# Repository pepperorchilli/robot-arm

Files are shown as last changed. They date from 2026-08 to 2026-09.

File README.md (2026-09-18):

# 五自由度机械臂 · 项目存档

本仓库包含机械臂项目的**两个阶段版本**，用于呈现完整的技术演进过程。

```
robot-arm 1/     2026-08-16 的版本（第一代）
robot-arm2/      当前版本（第二代）
```

---

## 为什么有两个版本

这不是"新旧替换"，而是**两次架构决策前后**的对比记录。

| | robot-arm 1 | robot-arm2 |
|---|---|---|
| **时间** | 2026-08-11 ~ 08-16 | 2026-09-18 起 |
| **定位** | 打通云端链路，实现公网遥控 | 解决抖动、补齐工程化 |
| **舵机驱动** | PCA9685 + 模拟舵机 | 升级中：总线舵机（STS3215） |
| **前端** | 原生 HTML/CSS/JS | Vue 3 + Vite |
| **数据存储** | JSON 文件 | MySQL |
| **接口文档** | 无 | OpenAPI / Swagger |
| **附加功能** | 官网 / 留言板 / PWA | 手势识别 / 力反馈接口 |

**关键差异**：第一代把系统"跑起来"了，但在静止时发现 5 个舵机会小幅抽搐——
根因是模拟舵机的脉宽被 WiFi 射频干扰。第二代换了**串行总线舵机**，
用带校验和的数字协议从**协议层免疫**这个问题，同时获得力反馈能力。

---

## 📁 robot-arm 1 —— 第一代（2026-08-16）

```
robot-arm 1/
├── 3D建模/              六个结构件的 STL（MG996R 尺寸，正在重新建模）
├── server/              云控服务器 + 官网（Node.js，JSON 存储）
├── servo-test/          基础固件（softAP 自建热点 + PCA9685）
├── arm-5servo/          直驱固件（绕开 PCA9685 的实验）
└── servo-direct-test/   单舵机诊断固件
```

**这一代解决了什么**：让 ESP32 主动连出到云服务器，实现公网远程控制。

**局限**：舵机静止时抖动；数据存 JSON 文件；前端为原生 JS。

> 📌 这是**冻结的快照**，仅作技术演进记录，不再更新。

---

## 📁 robot-arm2 —— 第二代（当前版本）

```
robot-arm2/
├── README.md            项目主页（功能介绍 / 架构 / 快速开始）
├── 技术文档.md           系统原理（含完整数据流追踪）
├── server/              云控服务器 + 官网（Node + MySQL + Vue 3）
├── gesture-control/     手势识别控制（Python + MediaPipe）
├── arm-cloud-bus/       云连接 + 总线舵机（当前主线）
└── arm-bus-servo/       总线舵机固件（含串口调试命令）
```

> 所有 MG996R 时代的固件（`arm-cloud/`、`servo-test/`、`arm-5servo/`、
> `servo-direct-test/`、`wifi-off-hold-test/`）与原 3D 模型
> 已归档到 `robot-arm 1/`，不在本目录中重复。

**这一代新增**：

- 🌐 手势识别控制（MediaPipe + OpenCV）
- 💾 MySQL 持久化 + 索引优化（扫描行数 49914 → 20）
- 🖥️ Vue 3 + Vite 重写前端
- 📖 OpenAPI / Swagger 接口文档
- 🔧 总线舵机升级（协议层免疫射频干扰 + 力反馈）
- 🔐 凭据隔离、设备鉴权、最小权限数据库账号

👉 **详细说明请进 [robot-arm2/README.md](robot-arm2/README.md)**

---

## 快速导航

| 我想看… | 去哪里 |
|---|---|
| 项目能做什么、怎么跑 | [robot-arm2/README.md](robot-arm2/README.md) |
| **第二代**系统是怎么运作的 | [robot-arm2/技术文档.md](robot-arm2/技术文档.md) |
| **第一代**系统 + **完整的抖动排查过程** | [robot-arm 1/技术文档.md](robot-arm%201/技术文档.md) |
| 每版固件为什么这么设计 | [固件演进记录.md](固件演进记录.md) |
| 抖动问题的诊断报告 | [抖动诊断结论.md](robot-arm%201/wifi-off-hold-test/抖动诊断结论.md) |
| 数据库怎么设计的 | [robot-arm2/server/DATABASE.md](robot-arm2/server/DATABASE.md) |

---

## 技术栈

| 层面 | robot-arm 1 | robot-arm2 |
|---|---|---|
| 嵌入式 | C++ / Arduino、ESP32-S3、I2C、PWM | ＋ TTL 串口总线协议 |
| 后端 | Node.js、Express、ws | ＋ MySQL、OpenAPI |
| 前端 | 原生 HTML/CSS/JS、PWA | ＋ Vue 3、Vite |
| AI | — | Python、MediaPipe、OpenCV |
| 部署 | Linux、Nginx、SSL | 同左 |

---

> ⚠️ **关于凭据**：两个版本中的 WiFi 密码、服务器地址、token 等敏感信息
> 均已抽离到 `secrets.h` / `config.js` 并加入 `.gitignore`，不入库。
> 模板见各自的 `.example` 文件。

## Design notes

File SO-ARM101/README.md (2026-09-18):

# SO-ARM101 机械结构模型（第三方）

本目录是 **SO-ARM101** 开源机械臂的 3D 模型文件，用于本项目第二代机械臂的结构件打印。

> ⚠️ **这不是本项目的原创内容**，是从上游开源项目下载的第三方素材。
> 保留在此是为了让结构件与配套固件、文档处于同一仓库，方便对照。

---

## 来源与许可

| | |
|---|---|
| **上游项目** | [TheRobotStudio/SO-ARM100](https://github.com/TheRobotStudio/SO-ARM100) |
| **设计方** | RobotStudio × Hugging Face（LeRobot 项目官方硬件） |
| **许可证** | **Apache License 2.0**（见本目录 [`LICENSE`](LICENSE)） |
| **下载日期** | 2026-09-18 |

Apache-2.0 允许再分发和修改，但要求：

- ✅ 保留版权声明与许可证副本 —— 已在本目录放置 `LICENSE`
- ✅ 标注是否做了修改 —— **本目录内容原样下载，未做任何修改**

---

## 目录内容

```
SO-ARM101/
├── LICENSE      Apache-2.0 许可证（上游原文件）
├── STL/         用于 3D 打印的模型文件
│   ├── Base_SO101.stl                  底座
│   ├── Base_motor_holder_SO101.stl     底座舵机支架
│   ├── Upper_arm_SO101.stl             上臂
│   ├── Under_arm_SO101.stl             下臂
│   ├── Rotation_Pitch_SO101.stl        旋转俯仰件
│   ├── Motor_holder_SO101_Base.stl     舵机支架（底座）
│   ├── Motor_holder_SO101_Wrist.stl    舵机支架（腕部）
│   ├── Wrist_Roll_SO101.stl            腕部旋转
│   ├── Wrist_Roll_Pitch_SO101.stl      腕部旋转俯仰
│   ├── Wrist_Roll_Follower_SO101.stl   腕部旋转（Follower 专用）
│   ├── Moving_Jaw_SO101.stl            活动爪
│   ├── Trigger_SO101.stl               扳机
│   ├── Handle_SO101.stl                手柄（Leader 臂用）
│   ├── Seeedstudio_Mounting_Plate_SO101.stl   厂商安装板
│   ├── WaveShare_Mounting_Plate_SO101.stl     厂商安装板
│   ├── Gauge_0.STL                     ★ 尺寸校验件
│   └── Gauge_tight_1.STL               ★ 尺寸校验件
└── STEP/        可编辑的 CAD 源文件（改模型时用）
```

---

## ⚠️ 打印前必读

### 1. 先打校验件

**别急着打全部零件。** 先打 `STL/Gauge_0.STL`（20 分钟），
拿它套一下 STS3215 舵机或标准乐高积木：

- 松紧合适 → 打印机精度够，可以打全部
- 太紧/太松 → **先校准打印机**，否则所有零件都白打

这一步能省下几十小时和一整卷耗材。

### 2. 只需要 Follower 臂的零件

SO-ARM101 有 **Follower（干活的）** 和 **Leader（手拖的遥操作臂）** 两个版本。

**只打印 Follower 需要的件。** `Handle_SO101.stl` 是 Leader 臂用的，本项目不需要。

### 3. 打印参数

见上游仓库的 `3DPRINT.md`，里面有推荐层高和填充率。

---

## 配套信息

| 项目 | 位置 |
|---|---|
| 舵机型号与采购清单 | [`../robot-arm2/arm-bus-servo/README.md`](../robot-arm2/arm-bus-servo/README.md) |
| 固件（总线舵机 + 云连接） | [`../robot-arm2/arm-cloud-bus/`](../robot-arm2/arm-cloud-bus/) |
| 系统技术文档 | [`../robot-arm2/技术文档.md`](../robot-arm2/技术文档.md) |

---

## 关于本项目的结构选型

第一代的机械结构是自建的（见 [`../robot-arm 1/3D建模/`](../robot-arm%201/3D建模/)），
但换总线舵机时发现 STS3215 的尺寸与原模型不匹配（宽 +5mm、长 +4.5mm、高 −7.9mm）。

与其重新设计并承担未经验证的风险，**直接采用经过大量用户验证的开源设计** ——
这是工程上的合理取舍：**能复用成熟方案时，不重复造轮子。**

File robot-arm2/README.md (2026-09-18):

# 六自由度机械臂 · 远程控制系统

一台 3D 打印的机械臂，支持**公网网页遥控**与**手势识别控制**，从硬件驱动到云端服务完整自建。

> 📷 *（建议在这里放一张机械臂实物照片 —— 面试官点进来第一眼看到的就是它）*

---

## 功能特性

| 功能 | 说明 |
|---|---|
| 🌐 **公网远程控制** | ESP32 主动连出，无需公网 IP、不用端口映射，随时随地用网页控制 |
| ✋ **手势识别控制** | 摄像头识别手势驱动机械臂，支持指令模式与位置跟随 |
| 🖥️ **Web 遥控台** | Vue 3 单页应用，滑块、预设姿态、精细微调 |
| 💬 **配套官网** | 首页 / 留言板 / 下载页，支持 PWA 安装到手机 |
| 📖 **在线 API 文档** | OpenAPI 3.0 + Swagger UI，可在线调试 |
| 🔧 **力反馈**（升级中） | 总线舵机回传电流，实现夹爪力度控制与碰撞检测 |

---

## 系统架构

```
┌─────────────────────────────────────────────────────┐
│  应用层    Vue 3 网页遥控  │  Python 手势识别            │
└──────────────────────┬──────────────────────────────┘
                       │ HTTP
┌──────────────────────▼──────────────────────────────┐
│  云服务层   Node.js + Express + WebSocket 中转         │
│            MySQL 数据持久化  │  OpenAPI 接口文档         │
└──────────────────────┬──────────────────────────────┘
                       │ WebSocket 长连接
┌──────────────────────▼──────────────────────────────┐
│  嵌入式层   ESP32-S3 固件（C++ / Arduino）             │
└──────────────────────┬──────────────────────────────┘
                       │ I2C（当前）/ TTL 串口总线（升级中）
┌──────────────────────▼──────────────────────────────┐
│  硬件层     PCA9685 驱动板  │  舵机 × 5  │  3D 打印结构  │
└─────────────────────────────────────────────────────┘
```

**为什么需要服务器中转？**
ESP32 在局域网里、没有公网 IP。让它**主动连出去**并保持长连接，服务器就能顺着这条连接把浏览器命令转发进来 —— 不需要端口映射，也不用内网穿透。这是物联网设备的标准做法。

> 完整技术说明见 **[技术文档.md](技术文档.md)** —— 包含从拖动滑块到舵机转动的完整数据流追踪。

---

## 快速开始

### 1. 启动服务器

```bash
cd server
npm run setup      # 安装前后端依赖
mysql -u root < schema.sql   # 建库建表（首次）
npm run build      # 构建前端
npm start
```

浏览器打开 http://localhost:3000

### 2. 烧录固件

```bash
cd arm-cloud
cp secrets.h.example secrets.h   # 填入 WiFi 和服务器地址
```

用 Arduino IDE 打开 `arm-cloud.ino` 烧录（开发板选 **ESP32S3 Dev Module**）。

### 3. 手势控制（可选）

```bash
cd gesture-control
uv run smoke_test.py        # 自检环境
uv run gesture_control.py   # 启动
```

---

## 目录导航

| 目录 | 内容 | 文档 |
|---|---|---|
| [`server/`](server/) | 云控服务器 + 产品官网（Node + MySQL + Vue） | [README](server/README.md) · [数据库设计](server/DATABASE.md) |
| [`server/web/`](server/web/) | Vue 3 遥控台前端 | [README](server/web/README.md) |
| [`gesture-control/`](gesture-control/) | 手势识别控制（Python + MediaPipe） | [README](gesture-control/README.md) |
| [`arm-cloud-bus/`](arm-cloud-bus/) | **云连接 + 总线舵机**（当前主线） | — |
| [`arm-bus-servo/`](arm-bus-servo/) | 总线舵机固件（含串口调试命令） | [README](arm-bus-servo/README.md) |

> **所有 MG996R 时代的固件与模型已归档到 [`../robot-arm 1/`](../robot-arm%201/)**
> —— `arm-cloud/`（云连接 + PCA9685）、`servo-test/`、`arm-5servo/`、
> `servo-direct-test/`、`wifi-off-hold-test/` 与原 `3D建模/`。
> 本目录只保留总线舵机方案，因为**换舵机只需要换固件**——
> 下面的 `server/` 和 `gesture-control/` 与舵机型号无关，一行都没改。

---

## 技术栈

| 层面 | 技术 |
|---|---|
| **嵌入式** | C++ / Arduino、ESP32-S3、I2C、PWM、TTL 串口协议、WebSocket 客户端 |
| **后端** | Node.js、Express、ws、MySQL、连接池、参数化查询 |
| **前端** | Vue 3（Composition API / SFC）、Vite、HTML/CSS/JS、PWA |
| **AI** | Python、MediaPipe、OpenCV |
| **数据库** | MySQL 索引优化、EXPLAIN 分析、N+1 查询消除、外键约束 |
| **接口文档** | OpenAPI 3.0、Swagger UI |
| **部署** | Linux、Nginx、SSL |

---

## 项目亮点

### 🔍 一次完整的硬件故障排查

机械臂静止时，5 个舵机会**小幅抽搐且不同步**。排查过程：

```
排除 PCA9685   → 拆掉改直驱，仍抖
排除舵机个体   → 全部都会抖
排除供电不足   → 5V 20A 余量充足，空载也抖
排除机械虚位   → 空载也抖
━━━━━━━━━━━━━━━━━━━━━━━━━━━━━━━━━━━━
决定性实验：关掉 WiFi 烧录 → 完全不抖
确诊：ESP32 的 2.4GHz 射频耦合进未屏蔽的信号线
```

**根因**：模拟舵机靠"量脉宽长度"决定角度，射频毛刺让脉宽被撑长/削短几微秒，舵机就当成一次角度变化。

**解决**：这是架构性矛盾，加电容电阻只是在信号完整性层面打消耗战。改用**串行总线舵机**——走数字协议且带校验和，噪声要么被电平阈值滤掉、要么校验失败被丢弃，属于**协议层免疫**。同时获得了力反馈能力。

> 完整报告：[抖动诊断结论.md](../robot-arm%201/wifi-off-hold-test/抖动诊断结论.md)（在第一代归档目录中）

### 📊 有实证的数据库优化

```
索引优化：扫描行数 49914 → 20    耗时 11.76ms → 0.30ms
N+1 消除：列表接口从 1+N 次查询 → 固定 2 次
```

跑 `npm run explain` 可复现完整的 EXPLAIN 对比与压测。

### 🔐 工程实践

- **设备鉴权**：ESP32 连接需携带 token，防止伪造设备劫持控制权
- **凭据隔离**：WiFi 密码等敏感信息抽到 `secrets.h` 并加入 `.gitignore`
- **最小权限**：数据库应用账号只有业务所需的增删改查权限
- **参数化查询**：所有用户输入走占位符，杜绝 SQL 注入
- **单元测试**：手势逻辑与留言板均有测试覆盖

---

## 硬件清单

| 部件 | 型号 |
|---|---|
| 主控 | ESP32-S3 |
| 舵机驱动 | PCA9685（16 路 PWM，I2C） |
| 舵机 | **Feetech STS3215 总线舵机 × 6**（7.4V，1/345 减速比）<br>*第一代用的是 MG996R × 5，已淘汰* |
| 供电 | 12.6V 锂电池 → 降压 7.4V（或 UBEC 5V） |
| 结构 | **SO-ARM101** 开源设计，3D 打印件 |

---

## 开发路线

> 每一版固件为什么这么做、被什么取代，见 **[固件演进记录.md](../固件演进记录.md)**

- [x] 基础网页遥控（softAP）
- [x] 云端化（WebSocket 主动连出，公网可控）
- [x] 设备鉴权与安全加固
- [x] 手势识别控制
- [x] Vue 3 前端重写
- [x] MySQL 持久化与性能优化
- [x] OpenAPI 接口文档
- [ ] 总线舵机升级（进行中）
- [ ] 力反馈（夹爪力度控制）
- [ ] 逆运动学与轨迹规划

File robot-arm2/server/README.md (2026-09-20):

# 机械臂云控服务器

ESP32 与浏览器/手势模块之间的中转服务器，同时托管产品官网。

---

## 系统架构

```
   Vue 网页遥控 ──┐
                  ├──HTTP──> 本服务器 ──WebSocket──> ESP32 ──I2C──> PCA9685 ──> 5 舵机
   Python 手势  ──┘
```

**为什么要服务器中转？**
ESP32 在局域网里，没有公网 IP。让 ESP32 主动用 WebSocket 连到服务器并保持长连接，
浏览器就能通过服务器把命令转发进去 —— 不需要端口映射，也不用内网穿透。

---

## 快速开始

```bash
# 1. 建库建表（首次）
mysql -u root < schema.sql

# 2. 装依赖（前后端一起）
npm run setup

# 3. 构建前端
npm run build

# 4. 启动
npm start
```

打开 http://localhost:3000

| 页面 | 地址 |
|---|---|
| 首页 | `/` |
| 遥控（Vue 3） | `/control` |
| 留言板 | `/messages` |
| 下载 | `/download` |
| **API 文档** | **`/api-docs`** |

---

## npm 脚本

| 命令 | 作用 |
|---|---|
| `npm start` | 启动服务器 |
| `npm run setup` | 安装前后端全部依赖 |
| `npm run build` | 构建 Vue 前端（产物到 `public/control/`） |
| `npm run dev:web` | Vue 开发模式（热更新，5173 端口） |
| `npm run init-db` | 建库建表 |
| `npm run migrate` | 把旧的 JSON 留言迁移到 MySQL |
| `npm run explain` | **SQL 优化实证**（EXPLAIN 对比 + 压测） |

---

## 目录结构

```
server/
├── server.js          # 入口：路由 + WebSocket 中转
├── swagger.js         # OpenAPI 文档配置
├── db.js              # MySQL 连接池
├── store.js           # 留言数据访问层
├── schema.sql         # 建库建表
├── config.js          # 配置（含密码，已被 gitignore）
├── config.example.js  # 配置模板
├── migrate.js         # 旧数据迁移
├── explain-demo.js    # SQL 优化实证
├── DATABASE.md        # 数据库设计文档
├── web/               # Vue 3 前端源码
└── public/            # 静态资源 + 前端构建产物
```

---

## 接口

完整文档见 **http://localhost:3000/api-docs**（Swagger UI，可在线调试）。

也可以直接取原始规范导入 Postman / Apifox：`GET /api-docs.json`

### 遥控

```
GET /set?servo=0&angle=90
```

| 参数 | 说明 |
|---|---|
| `servo` | 0~5，依次为 底座 / 肩部 / 肘部 / 腕俯仰 / 腕旋转 / 夹爪 |
| `angle` | 0~180（度） |

ESP32 未连接时返回 **503** —— 前端和手势模块以此判断设备是否在线。

### 留言板

| 方法 | 路径 | 说明 |
|---|---|---|
| GET | `/api/messages` | 留言列表（含回复） |
| POST | `/api/messages` | 发表留言 |
| POST | `/api/messages/:id/reply` | 回复（需管理员身份） |
| DELETE | `/api/messages/:id` | 删除（需管理员身份） |

### 登录与权限

**登录一次即为管理员**，之后控制机械臂、回复留言、删除留言都不再需要输密码。

| 接口 | 说明 |
|---|---|
| `POST /api/login` | 密码换 token，写入 httpOnly cookie |
| `POST /api/logout` | 退出登录 |
| `GET /api/auth` | 查询登录状态 |

- 机械臂的 `/set` 和控制台需要登录（防止陌生人乱动舵机）
- 留言板**浏览和发留言是公开的**，只有回复/删除需要管理员身份
- 登录接口有频率限制：同一 IP 十分钟内失败 5 次封禁 15 分钟

> 手势模块等本地程序用 `X-Auth-Token` 头携带 token（见 `gesture-control/arm_client.py`）。

---

## WebSocket

ESP32 连进来时要带暗号：

```
ws://<服务器地址>/?token=<ESP32_TOKEN>
```

token 不匹配会被直接断开。见 `config.js` 与 ESP32 固件里的对应配置。

---

## 配置

`config.js` **含密码，已被 `.gitignore` 排除**。部署时用环境变量覆盖：

| 环境变量 | 说明 |
|---|---|
| `PORT` | 服务端口（默认 3000） |
| `ADMIN_PASSWORD` | 留言管理密码 |
| `ESP32_TOKEN` | ESP32 连接暗号 |
| `DB_HOST` / `DB_PORT` / `DB_USER` / `DB_PASSWORD` / `DB_NAME` | MySQL 连接信息 |

模板见 `config.example.js`。

---

## 相关文档

- 数据库设计与 SQL 优化 → [`DATABASE.md`](DATABASE.md)
- Vue 前端 → [`web/README.md`](web/README.md)
- 手势识别 → [`../gesture-control/README.md`](../gesture-control/README.md)
- 总线舵机升级 → [`../arm-bus-servo/README.md`](../arm-bus-servo/README.md)

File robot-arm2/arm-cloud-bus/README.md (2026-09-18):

# 云连接 + 总线舵机固件（当前主线）

把机械臂接入云端，实现公网远程控制。**这是最终要用的固件。**

---

## 它是什么

`arm-cloud`（云连接）和 `arm-bus-servo`（总线舵机）的合并版本：

| | 来源 |
|---|---|
| WiFi STA + WebSocket 客户端 + token 鉴权 | `arm-cloud/` |
| STS3215 串行总线驱动 | `arm-bus-servo/` |

```
浏览器 ──HTTP──> Nginx ──> Node 服务器 ──WebSocket──> 本固件 ──TTL总线──> 6 个舵机
```

---

## 和其他固件的区别

| 固件 | 舵机 | 联网方式 |
|---|---|---|
| `arm-bus-servo/` | 总线舵机 | softAP 自建热点（局域网直连） |
| `arm-cloud/` | PCA9685 + 模拟舵机 | STA 主动连出（可公网） |
| **`arm-cloud-bus/`** | **总线舵机** | **STA 主动连出（可公网）** |

前两个是第一代/过渡方案，本固件是最终形态。

---

## 一、首次配置

### 1. 创建凭据文件

```bash
cd arm-cloud-bus
cp secrets.h.example secrets.h
```

编辑 `secrets.h`：

```c
#define WIFI_SSID       "你的WiFi名称"
#define WIFI_PASSWORD   "你的WiFi密码"
#define SERVER_HOST     "你的服务器IP"       // 局域网测试时填电脑的局域网 IP
#define SERVER_PORT     80                  // ⚠️ 见下方说明
#define ESP32_TOKEN     "和服务器 config.js 里一致"
```

### 2. ⚠️ 端口填 80（如果前面有 Nginx）

| 部署方式 | `SERVER_PORT` |
|---|---|
| 直接连 Node（局域网测试） | `3000` |
| 通过 Nginx（服务器部署） | **`80`** |

### 3. ⚠️ WebSocket 路径是 `/ws`，不是 `/`

固件里已经写好了，这里说明原因：

> Nginx 无法按请求头区分 `location`，而 `/` 要留给静态首页。
> 所以让 ESP32 连到独立的 `/ws` 路径，Nginx 就能按路径分流。
>
> **服务器只校验 token 不校验路径**，所以改路径不需要动后端代码。

### 4. ⚠️ ESP32 只支持 2.4GHz

连不上 5GHz 频段的 WiFi。连不上时先用手机热点试。

---

## 二、接线

```
                    ┌─────────────────────────┐
                    │     舵机总线（3pin）      │
                    └──┬────┬────┬────┬────┬──┘
                       │    │    │    │    │
                     [舵1] [舵2] [舵3] [舵4] [舵5] [舵6]
                       │
  ESP32 GPIO17 (TX) ───┼─── DATA
  ESP32 GPIO16 (RX) ───┘
  ESP32 GND ─────────────── 电源 GND（共地，必须）
  ESP32 供电 ────────────── 独立 USB（⚠️ 不要和舵机共用）

  6 个舵机 V+ / GND ─────── 5V（或 7.4V）电源，**并联**取电
```

### 三条铁律

1. **必须共地** —— ESP32 的 GND 和舵机电源的 GND 接一起
2. **ESP32 独立供电** —— 舵机峰值电流会把共用电源拉低，导致 ESP32 复位
3. **电源并联，不走串联** —— 串联时第一个舵机的接口要扛全部下游电流，会烧

### 回读（力反馈）需要额外加一个电阻

```
DATA ──[1kΩ]── 3.3V
```

总线是半双工，发完要把 TX 释放成高阻态舵机才能回话。不加也能控制，只是读不到位置和电流。

---

## 三、烧录与验证

1. Arduino IDE 打开 `arm-cloud-bus.ino`，开发板选 **ESP32S3 Dev Module**
2. 串口监视器（115200）应看到：

```
连接 WiFi: xxx ....
✅ WiFi 已连接
   本机 IP: 192.168.x.x
正在连接服务器 xxx:80 …
✅ 已连上服务器
```

3. **服务器端**应看到：

```
✅ ESP32 认证通过
✅ 这是 ESP32，已登记
```

4. 浏览器打开 `http://<服务器IP>/control`，**登录后**拖动滑块

---

## 四、出问题对照表

| 现象 | 原因 |
|---|---|
| WiFi 连不上 | 用了 5GHz 频段 / 密码错 |
| 连不上服务器 | IP/端口填错 / 服务器没启动 / 防火墙 |
| 反复「已连上」又「断开」 | **token 不匹配**。以服务器日志为准 |
| 连上了但舵机不动 | 舵机没供电 / ID 没改（出厂全是 1） |
| 6 个舵机同时乱动 | **ID 冲突** —— 必须逐个改成 1~6 |
| 读位置返回 0xFFFF | 缺 1kΩ 上拉电阻 |

> **调试提示**：token 不对时 WebSocket 握手会先成功、服务器随即断开。
> 所以固件串口会看到「已连上」紧接着「断开」反复循环 —— 这不是网络问题。
> **以服务器日志为准**，它会明确打印拒绝原因。

---

## 五、协议速查

### 关节与舵机编号

| 编号 | 关节 | SO-ARM101 对应 |
|---|---|---|
| 0 | 底座旋转 | shoulder_pan |
| 1 | 肩部 | shoulder_lift |
| 2 | 肘部 | elbow_flex |
| 3 | 腕俯仰 | wrist_flex |
| 4 | 腕旋转 | wrist_roll |
| 5 | 夹爪 | gripper |

### 用到的寄存器

| 地址 | 名称 | 说明 |
|---|---|---|
| 0x28 | Torque Enable | 0=关扭矩，1=开 |
| 0x2A | Goal Position | 目标位置 0–4095（2 字节） |
| 0x2C | Goal Time | 到达目标用时（ms，舵机内部平滑） |
| 0x38 | Present Position | 当前位置（只读，需上拉） |
| 0x3C | Present Load | 当前负载（只读，**力反馈用这个**） |

### 为什么不用软件插补

PCA9685 版需要主循环逐度推进，因为模拟舵机只能"给多少脉宽转多少角度"。

总线舵机可以**把「目标位置 + 到达时间」一起下发**，舵机内部自己按时间平滑走位。

所以本固件**不需要 `stepMotion()`**，一条 `SYNC_WRITE` 让 6 轴同时按各自速度运动 ——
**选对架构，代码反而更简单。**

---

## 相关文档

- 服务器部署 → [`../server/README.md`](../server/README.md)
- 总线舵机硬件与调试 → [`../arm-bus-servo/README.md`](../arm-bus-servo/README.md)
- 网站整体部署 → 站点仓库的 `docs/DEPLOY.md`

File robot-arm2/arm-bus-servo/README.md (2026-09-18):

# 换成总线舵机（STS3215）

从 MG996R（模拟 PWM）升级到 Feetech STS3215（串行总线闭环），根治 WiFi 射频引起的静止抖动。

---

## 一、为什么要换

**MG996R 的抖动是架构性的，不是接线的锅。**

模拟舵机靠「量脉宽长度」决定角度：脉宽 0.5–2.5ms 对应 0–180°。
ESP32 的 WiFi 射频（2.4GHz）耦合进信号线，脉宽被撑长或削短几个微秒，
舵机就把它当成一次角度变化 → 静止时小幅抽搐。

加电容电阻是**在信号完整性层面压制噪声**，能改善但很难根治。

**STS3215 走数字串口协议**，每条指令带校验和：

```
0xFF 0xFF ID LENGTH INSTRUCTION 参数... 校验和
```

噪声混进来，要么被数字电平阈值（0/1）直接滤掉，要么造成校验失败
—— 舵机**直接丢弃这条指令**，永远不会把噪声翻译成角度。

**这是协议层面的免疫，不是靠滤波压制。** 所以静止时纹丝不动。

---

## 二、采购清单

| 项目 | 型号 | 数量 | 单价 | 小计 |
|---|---|---|---|---|
| 总线舵机 | Feetech **STS3215** | 5 | ~¥65 | ¥325 |
| 降压模块 | 12.6V → 7.4V，**≥5A** | 1 | ~¥15 | ¥15 |
| 调试板（改 ID 用） | Feetech **FE-URT-1** | 1 | ~¥30 | ¥30 |
| | | | | **≈ ¥370** |

**建议先买 1 个**（¥65）验证协议和效果，确认不抖、通信正常，再补齐剩下 4 个。

> 不买调试板也行 —— 本固件内置了串口改 ID 命令。但官方调试板是图形界面，
> 改 ID / 扫描 / 试转都更省事，¥30 值得。

### 不再需要的东西

- ❌ UBEC 5V 20A（电压不对了）
- ❌ 2进12出分电盒（总线只需要一条线手拉手，用不上分电）
- ❌ PCA9685（完全拆掉）
- ❌ 100Ω 串阻、滤波电容（问题在协议层解决了，这些不用了）

---

## 三、供电改造（最容易踩的坑）

### ⚠️ STS3215 是 7.4V，不是 5V

| | MG996R | STS3215 |
|---|---|---|
| 额定电压 | 4.8–7.2V | **6–8.4V（额定 7.4V）** |
| 静态电流 | ~10mA | ~30mA |
| 堵转电流 | ~1.5A | **~3A** |

**6 个舵机同时动作，峰值电流可达 10A 以上。** 供电必须够粗。

### 两个方案

**方案 A（推荐）：2S 锂电直驱**
买个 2S 锂电池（7.4V），直连舵机总线。最简单，不用降压模块。

**方案 B：现有 12.6V 锂电降压**
```
12.6V 锂电 ──→ 降压模块(12.6V→7.4V, ≥5A) ──→ 舵机总线 V+
```
注意要买**能输出 5A 以上**的模块，普通小模块扛不住。

### 接线粗细

- 供电线 / 地线：**≥20AWG**（越短越粗越好）
- 信号线（DATA）：普通杜邦线即可，电流很小

---

## 四、接线

```
                    ┌─────────┐
   ESP32-S3         │ 舵机总线 │
                    └────┬────┘
   GPIO17 (TX) ──[1kΩ]───┤  ← 上拉电阻，回读时才需要
   GPIO16 (RX) ──────────┤
   GND         ──────────┤
                         │
   7.4V ─────────────────┤ V+
   GND  ─────────────────┤ GND
                         │
        6 个舵机 DATA 全部并联到这条总线
        6 个舵机 V+ / GND 分别并到 7.4V / GND
```

**要点：**

1. **共地必须做**：ESP32 的 GND 要和舵机电源的 GND 接在一起
2. **只发指令**（位置控制）→ TX 直连即可
3. **要回读**（读角度/力反馈）→ 必须加 **1kΩ 上拉到 3.3V**
   - 总线是半双工的，ESP32 发完要把 TX 释放成高阻态，舵机才能回话
   - 固件里的 `readReg()` 已实现这个逻辑，但硬件上拉不能省
4. 总线总长度尽量控制在 **1 米以内**

---

## 五、四步验证法（拿到货先做这个）

**别一上来就跑整套。** 按顺序逐个确认，出问题好定位。

### 第 1 步：确认能发现舵机

只接**一个**舵机。烧录固件，打开串口监视器（115200），输入：

```
scan
```

应该看到：

```
扫描总线上 1~10 号…
  ✅ 发现舵机 ID = 1
```

> ❌ 扫不到？检查：波特率是不是 1Mbps、TX/RX 有没有接反、供电是不是 7.4V、有没有共地。

### 第 2 步：确认能转动

```
move 1 90
```

舵机应该平滑转到中位。再试：

```
move 1 0
move 1 180
```

**这一步最重要** —— 如果这里就不抖，说明协议层免疫生效了。

### 第 3 步：改 ID

出厂**所有舵机都是 ID=1**，必须逐个改成 1~5，否则总线冲突。

每次**只接一个舵机**，改完拔下来换下一个：

```
torque 1 0      # 先关扭矩（改 EEPROM 前必须关）
id 1 1          # 第一个：保持不变，跳过
id 1 2          # 第二个：改成 2 号
id 1 3          # 第三个：改成 3 号
id 1 4          # 第四个
id 1 5          # 第五个
```

改完**断电重启**才生效。

> 用 FE-URT-1 调试板的话，图形界面点几下就行，不用敲命令。

### 第 4 步：整套联调

6 个舵机全部接到总线，改好 `SERVO_ID[]` 数组，重启后：

```
center          # 全部回中，观察是否还有抽搐
all 45          # 全部转到 45°
```

**静止状态下观察 30 秒 —— 应该纹丝不动。**

### 第 5 步：开启网页控制

```
w
```

串口会打印热点和网址，浏览器打开即可用滑块控制。

---

## 六、和现有系统对接

**好消息：Node 服务器和手势模块一行都不用改。**

```
手势模块 ──┐
           ├──HTTP──> Node 服务器 ──WebSocket──> ESP32 ──总线──> 6 个舵机
网页遥控 ──┘
```

上层只跟 `/set?servo=i&angle=a` 这个接口打交道，底层是 PCA9685 还是总线舵机，
对它们完全透明。

**唯一要改的是 ESP32 固件**（就是这个 sketch）。

> 注意：当前 sketch 是**独立热点 + 自带网页**的版本（和 `servo-test.ino` 一致）。
> 如果要接入你的云服务器（WebSocket 中转），需要把 `server.js` 那套
> WebSocket 客户端逻辑合并进来 —— 这是下一步的事。

---

## 七、协议速查

### 包结构

```
[0]   0xFF        帧头
[1]   0xFF        帧头
[2]   ID
[3]   LENGTH = 参数个数 + 2
[4]   指令
[5..] 参数
[末]  校验和 = ~(ID + LENGTH + 指令 + 全部参数) & 0xFF
```

### 用到的指令

| 指令 | 值 | 说明 |
|---|---|---|
| PING | 0x01 | 测试舵机是否在线 |
| READ | 0x02 | 读寄存器 |
| WRITE | 0x03 | 写寄存器 |
| SYNC_WRITE | 0x83 | 广播同步写（多舵机同时到达） |

### 用到的寄存器

| 地址 | 名称 | 说明 |
|---|---|---|
| 0x05 | ID | 舵机 ID（EEPROM，改完需重启） |
| 0x28 | Torque Enable | 0=关扭矩，1=开 |
| 0x2A | Goal Position | 目标位置 0–4095（2 字节） |
| 0x2C | Goal Time | 到达目标用时（ms，硬件平滑） |
| 0x38 | Present Position | 当前位置（只读） |
| 0x3C | Present Load | 当前负载（只读）→ **力反馈用这个** |

### 位置 ↔ 角度

```
0     → 0°
2048  → 180°（机械中位）
4095  → 360°
```

本固件只用了 0–2048 这半个量程（对应 0–180°），预留另一半给需要更大行程的关节。

### 波特率寄存器（0x06）

| 值 | 波特率 |
|---|---|
| 0 | 1,000,000（**出厂默认**） |
| 1 | 500,000 |
| 2 | 250,000 |
| 3 | 128,000 |
| 4 | 115,200 |

---

## 八、常见问题

| 现象 | 可能原因 |
|---|---|
| `scan` 扫不到任何舵机 | 波特率不对 / TX·RX 接反 / 没共地 / 供电不足 |
| 舵机嗡嗡响但不动 | 电压不够（低于 6V）/ 扭矩没开 |
| 多个舵机同时乱动 | **ID 冲突**（出厂都是 1，必须逐个改） |
| 改 ID 后没反应 | 没断电重启 / 改 ID 前没关扭矩 |
| 读位置返回 0xFFFF | 缺 1kΩ 上拉电阻 |
| 某个舵机偶尔丢指令 | 总线太长 / 线太细 / 供电跌落 |

---

## 九、力反馈怎么用

拿到力反馈后，可以做的事：

```cpp
uint16_t load = readLoad(夹爪舵机ID);   // 负载 ≈ 力矩

// 夹爪抓握力度控制：抓住物体后，读到的负载会上升
// 检测到负载超过阈值 → 停止闭合 → 实现"抓而不碎"
```

典型应用：
- **夹爪力度控制**：抓鸡蛋不碎、抓铁块不掉
- **碰撞检测**：负载突增说明撞到东西了
- **堵转保护**：负载超限就停机，保护舵机

这是 MG996R 完全做不到的（它只有一根信号线进，什么都不回）。

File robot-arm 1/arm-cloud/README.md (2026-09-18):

# 云连接版固件

让 ESP32 **主动连出去**，接入 Node 服务器，实现浏览器远程控制。

---

## 和其他 sketch 的区别

| sketch | 模式 | 控制方式 |
|---|---|---|
| `servo-test/` | `WiFi.softAP` 自建热点 | 浏览器直连 ESP32 的 IP |
| `arm-5servo/` | 自建热点 | 直驱舵机 |
| `arm-bus-servo/` | 自建热点 | 总线舵机 |
| **`arm-cloud/`** | **`WIFI_STA` 连路由器** | **经服务器中转，可公网访问** |

前几个只能局域网直连。这个能穿透到公网——**因为 ESP32 主动往外连，不需要公网 IP，也不用端口映射**。

---

## 数据流

```
浏览器 ──HTTP──> Node 服务器 ──WebSocket 长连接──> ESP32 ──I2C──> PCA9685 ──> 舵机
```

---

## 一、首次配置

### 1. 创建凭据文件

```bash
cd arm-cloud
cp secrets.h.example secrets.h
```

编辑 `secrets.h`，填上：

```c
#define WIFI_SSID       "你的WiFi名称"
#define WIFI_PASSWORD   "你的WiFi密码"
#define SERVER_HOST     "192.168.1.100"      // 见下方"查电脑 IP"
#define SERVER_PORT     3000
#define ESP32_TOKEN     "change-me-to-a-random-token"
```

> ⚠️ `secrets.h` 已在 `.gitignore` 中，**不会提交到 Git**。
> 之前你的 WiFi 密码就是因为写死在固件里、仓库又是公开的而泄露过。
> 永远不要把真实密码写进 `secrets.h.example`（那个文件是要提交的）。

### 2. 确认 token 一致

`secrets.h` 里的 `ESP32_TOKEN` 必须和 `server/config.js` 里的 `ESP32_TOKEN` **完全一致**，否则服务器会直接断开连接。

### 3. ⚠️ ESP32 只支持 2.4GHz

连不上 5GHz 频段的 WiFi。如果连不上，先用手机热点试（手机热点一般是 2.4G）。

---

## 二、局域网测试（推荐先做这步）

不用租服务器，电脑上跑就行。

### 第 1 步：查你电脑的局域网 IP

```bash
# macOS
ipconfig getifaddr en0
# 输出类似 192.168.1.100
```

> 有线和无线网卡不同：Wi-Fi 是 `en0`，网线是 `en1`（不确定就跑 `ifconfig | grep "inet "`）。

### 第 2 步：把 IP 填进 `secrets.h` 的 `SERVER_HOST`

### 第 3 步：启动服务器

```bash
cd server
npm run build     # 如果改过 Vue 前端
npm start
```

看到 `服务器运行在 http://localhost:3000` 和 `✅ 数据库连接正常` 即可。

### 第 4 步：烧录固件

串口监视器（115200）应该看到：

```
连接 WiFi: 你的WiFi名称 ....
✅ WiFi 已连接
   本机 IP: 192.168.1.123
正在连接服务器 192.168.1.100:3000 …
✅ 已连上服务器
```

**同时服务器那边**应该打印：

```
✅ ESP32 认证通过
✅ 这是 ESP32，已登记
```

> ❌ 如果服务器打印 `有设备尝试连接，但 token 错误` —— 说明两边的 token 不一致。
> ❌ 如果什么也不打印 —— ESP32 没连上，检查 IP、端口、防火墙。

### 第 5 步：打开网页控制

浏览器访问 **http://localhost:3000/control**，拖动滑块。

- 舵机应该跟着动
- 到位后服务器日志会打印 `ESP32 回报: 0:90,1:45,...`

> macOS 防火墙可能拦截：系统设置 → 网络 → 防火墙 → 允许 node 接受传入连接。

---

## 三、公网部署（以后再做）

局域网验证通过后，搬到云服务器只需**改一行**：

1. 租一台云服务器（学生机约 ¥10/月）
2. 部署 Node + MySQL + Nginx + SSL（见 `server/README.md`）
3. 把 `secrets.h` 里的 `SERVER_HOST` 改成公网 IP 或域名
4. 重新烧录

其余代码**一行都不用动**。

---

## 四、技术要点

### 1. 非阻塞运动控制

旧版本用 `while` + `delay` 逐个舵机走步，问题有二：

- `delay` 期间整个 `loop()` 卡住，**WebSocket 收不到新消息、心跳也发不出去**，服务器会以为设备掉线
- 5 个舵机只能一个一个动，没法协调

改成主循环里「每隔 `STEP_DELAY` 走一步」：

```cpp
void loop() {
  ws.loop();       // 必须高频调用
  stepMotion();    // 所有舵机同时朝各自目标推进
}
```

所有舵机并行推进，`loop()` 始终保持响应。

### 2. 断线自动重连

```cpp
ws.setReconnectInterval(5000);
ws.enableHeartbeat(15000, 3000, 2);
```

心跳很重要：家用路由器和运营商的 NAT 会掐断长时间空闲的 TCP 连接。
没有心跳的话，连接看着还在，实际已经死了，命令发不进去。

### 3. 到位回报

所有舵机都到达目标后，固件主动回传一次状态：

```
0:90,1:45,2:120,3:90,4:150
```

网页端可以据此显示"已到位"。

---

## 五、排错

| 现象 | 原因 |
|---|---|
| WiFi 连不上 | 用了 5GHz 频段 / 密码错 / 信号太弱 |
| 连不上服务器 | `SERVER_HOST` 填错 / 服务器没启动 / 防火墙拦截 |
| token 错误 | 两边 token 不一致 |

> **调试提示**：token 不对时，WebSocket 的**握手会先成功**，然后服务器立刻把连接断开。
> 所以固件串口会看到「已连上服务器」紧接着「与服务器断开」，反复循环——
> 这不是网络问题，是 token 不匹配。**以服务器日志为准**，它会明确打印
> `❌ 有设备尝试连接，但 token 错误，已拒绝`。
| 连上但舵机不动 | 命令格式不对（应为 `"0:45"`）/ 舵机供电没接 |
| 偶尔断开重连 | 正常，心跳机制会自愈；频繁断检查 WiFi 信号 |
| 编译报错找不到 secrets.h | 忘了 `cp secrets.h.example secrets.h` |

---

## 相关文档

- 服务器部署 → [`../server/README.md`](../server/README.md)
- 数据库设计 → [`../server/DATABASE.md`](../server/DATABASE.md)
- 总线舵机升级 → [`../arm-bus-servo/README.md`](../arm-bus-servo/README.md)
- 抖动问题诊断 → [`../wifi-off-hold-test/抖动诊断结论.md`](../wifi-off-hold-test/抖动诊断结论.md)

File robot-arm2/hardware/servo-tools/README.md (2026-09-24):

# 阶段一：台面配置舵机（微雪转接板 + Mac）

目标：把一颗舵机接上、确认通信、改好 ID。
这一步是**一次性的**——ID 写进 EEPROM，掉电不丢。六个舵机各做一遍就完了。

## 当前已确认的环境

| 项 | 值 |
|---|---|
| 转接板 | 微雪 Bus Servo Adapter (A) |
| USB 芯片 | CH343P（Vendor ID `0x1a86`） |
| 串口 | **`/dev/cu.usbmodem5B8E1149761`** |
| 驱动 | ✅ **不用装**，macOS 自带 CDC 驱动已认 |
| pyserial | ✅ 已装（3.5） |

> 串口名带 `5B8E114976` 是这块板的序列号，换 USB 口不会变。

---

## ⚠️ 动手前必读：电压

原理图确认过，**舵机电源轨 = DC 输入直通**（转接板上的 H3/H5 直接接 `DC_IN0`）。
板上那套降压只给逻辑供电，不碰舵机。**所以喂多少伏，舵机就吃多少伏。**

| | 电压 |
|---|---|
| 转接板丝印标的输入 | 9 ~ 12.6V |
| **C001** 实际范围 | **4 ~ 7.4V** |

**丝印那个 9~12.6V 是给 C047（12V 版）写的。你现在是 C001，接 12V 会烧。**

👉 **DC 接 5 ~ 7.4V。** 桶形插头是 **5.5×2.1mm 中心正极**，极性反了同样烧。

### 台面测试用什么电源

**直接用一代那套里现成的 UBEC 5V 输出**，接到绿色端子就行（端子能夹裸线，不用桶形插头）。
只测一颗舵机、而且只是设 ID 不使劲，5V 完全够——扭矩在这里无所谓。

> 这颗 C001 是**台面练手件**，最终手臂用的是 **6 颗 C047（12V）**。
> 两者协议和寄存器完全一样，所以这里学到的每一步都能原样搬到 C047 上。
> 但 **C047 到货后，别把这颗 C001 接进手臂的总线**——12.6V 会烧了它。

---

## 接线

```
   Mac ──USB-C──▶ ┌──────────────┐
                  │  微雪转接板   │─── 3针 ──▶ 舵机
   DC 5~7.4V ───▶ │              │   DC_IN0 / GND / DATA
                  └──────────────┘
```

1. **舵机** 3 针线 → 转接板的**总线口**（H3 或 H5，不是 UART 口）。
   丝印对应：`DC_IN0` / `GND` / `DATA`
2. **USB-C** → Mac（这根只喂板上逻辑 + 提供串口，**不给舵机供电**）
3. **DC 5~7.4V** → 桶形座 或 绿色端子。**最后再接，接完再上电**

> USB 和 DC **必须同时接**。只插 USB 的话舵机没电，扫描会一个都找不到。

---

## 步骤

先切到工具目录：

```bash
cd "/Users/qiudai/Desktop/机器人研究(vscode)/robot-arm2/hardware/servo-tools"
```

### 第 1 步：确认串口 + 扫描舵机

```bash
python3 bench.py scan
```

- 看到 `✓ 串口已打开` + `✅ 发现舵机：ID = 1` → **接线全对，可以往下走**
- 看到 `一个舵机都没回应` → 按脚本打印的清单逐条排查

### 第 2 步：读状态，确认这颗舵机是好的

```bash
python3 bench.py info /dev/cu.usbmodem5B8E1149761 1
```

会打印位置 / 速度 / 负载 / 电压 / 温度 / 电流。
**重点看电压**——应该和你 DC 输入的电压吻合（比如给 5V，这里就是 ~5.0V）。
对不上说明供电有问题。

### 第 3 步：改 ID

**出厂 ID 全是 1，六颗全一样。必须一个个改。**

```bash
python3 bench.py id /dev/cu.usbmodem5B8E1149761 1 2
```

改完**拔掉 DC 再插回**（让新 ID 生效），然后验证：

```bash
python3 bench.py info /dev/cu.usbmodem5B8E1149761 2
```

### 第 4 步：测转向

```bash
python3 bench.py move /dev/cu.usbmodem5B8E1149761 2 90
```

不动的话先补一条使能扭矩：

```bash
python3 bench.py torque /dev/cu.usbmodem5B8E1149761 2 1
```

### 第 5 步：松力，换下一颗

改 ID 前最好让舵机能自由转动：

```bash
python3 bench.py torque /dev/cu.usbmodem5B8E1149761 2 0
```

然后重复第 1~5 步，把 ID 改成 3、4、5、6。

---

## 六个舵机的 ID 分配

| ID | 关节 |
|---|---|
| 1 | 底座旋转 |
| 2 | 肩部俯仰 |
| 3 | 肘部 |
| 4 | 腕俯仰 |
| 5 | 腕旋转 |
| 6 | 夹爪 |

> 顺序要和固件里的 `SERVO_ID[]` 数组一致，否则装到手臂上会动错关节。

---

## 为什么不用官方的 ping.py / change_id.py

官方脚本有两个坑，原样跑一定失败：

1. **`ping.py` 里写 `SCS_ID = 254`** —— 总线上没有这个 ID（有效范围 0~253，你的舵机是 1），
   结果是发出去等回应、超时失败。你会误以为接线错了。
2. **端口硬编码**（`DEVICENAME = 'COM73'`）—— 每换一台电脑就得回去改文件。

`bench.py` 把这两件事都变成参数，端口和 ID 从命令行传，不用改文件。

> 另外官方包里那个 `stservo-env/` 虚拟环境是 **Windows 的**（里面是 `Scripts/python.exe`），
> Mac 上用不了，直接忽略。

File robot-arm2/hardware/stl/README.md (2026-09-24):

# SO-ARM101 Follower 打印件

**只做 Follower（从动臂），不做 Leader（手握示教手柄）。**

我们的输入源是 WiFi + 网页控制台 + 手势识别，本身就是一套"人造输入设备"，
已经替代了 Leader 的功能。省下的：3 个打印件、6 个舵机、1 块控制板、1 个电源、1 条 USB 线。

来源：<https://github.com/TheRobotStudio/SO-ARM100> — `STL/SO101/Individual/`

## 零件清单（11 件）

| 文件 | 外形尺寸 X×Y×Z (mm) | 实体体积 | 承力 |
|---|---|---|---|
| `WaveShare_Mounting_Plate_SO101.stl` | 51.0 × 42.0 × 7.6 | 9.1 cm³ | 否 |
| `Base_SO101.stl` | 110.9 × 72.0 × 87.0 | 122.7 cm³ | 低 |
| `Base_motor_holder_SO101.stl` | 47.6 × 31.4 × 80.2 | 23.7 cm³ | 低 |
| `Motor_holder_SO101_Base.stl` | 28.0 × 38.1 × 55.1 | 13.3 cm³ | **是** |
| `Rotation_Pitch_SO101.stl` | 59.8 × 84.2 × 46.0 | 68.8 cm³ | **是** |
| `Upper_arm_SO101.stl` | 142.1 × 24.5 × 67.3 | 117.3 cm³ | **是** |
| `Motor_holder_SO101_Wrist.stl` | 28.0 × 36.9 × 56.4 | 13.9 cm³ | **是** |
| `Under_arm_SO101.stl` | 130.7 × 24.0 × 64.4 | 92.9 cm³ | **是** |
| `Wrist_Roll_Pitch_SO101.stl` | 62.3 × 35.7 × 77.8 | 32.3 cm³ | 低 |
| `Wrist_Roll_Follower_SO101.stl` | 65.2 × 52.0 × 105.4 | 56.6 cm³ | 低 |
| `Moving_Jaw_SO101.stl` | 22.3 × 92.0 × 48.0 | 20.7 cm³ | 低 |

合计实体体积 **571.3 cm³**。

> 尺寸是 STL 里的原始朝向。单件文件大概率是**装配朝向**，
> 切片时要自己转到"Z 朝上、少支撑"的姿态再打。

## 打印参数

官方基准：

- 材料 **PLA+**
- 0.4mm 喷嘴 / 0.2mm 层高，或 0.6mm 喷嘴 / 0.4mm 层高
- 填充 **15%**
- 支撑开 everywhere，但忽略与水平夹角大于 45° 的斜面
- **水平轴的螺丝孔里不能有支撑**

针对「结实稳固」的调整：上表标「是」的承力件填充提到 **30%**、壁厚 **4 圈**；
其余件保持 15%。承力件占了大头（402 / 571 cm³，约 70%），所以整机不会重多少，
但关节孔位不容易被舵机力矩拉裂——这是 SO-ARM 用 PLA 最常见的失效点。

**耗料预估**：15% 全件 ≈ 300–370g；承力件 30% ≈ 390–480g。备 1kg 一卷有余量。

## 先打校准规

别跳过。打废一整盘比打废两个小方块贵得多。

```bash
cd hardware/stl
curl -sSLO https://raw.githubusercontent.com/TheRobotStudio/SO-ARM100/main/STL/Gauges/Gauge_0.STL
curl -sSLO https://raw.githubusercontent.com/TheRobotStudio/SO-ARM100/main/STL/Gauges/Gauge_tight_1.STL
```

已经下好了，就是本目录里的 `校准规_Gauge_0.STL` / `校准规_Gauge_tight_1.STL`。
插一下舵机，松紧合适再开打整臂。官方对照教程：<https://youtu.be/dss8E3DG2rA>

## 配套采购（已定）

| 项 | 型号 | 数量 | 备注 |
|---|---|---|---|
| 舵机 | STS3215 **C047**（12V / 30kg·cm / 1/345 减速比） | **6** | Follower 六个关节**同一型号**，不用配比 |
| 台面练手件 | STS3215 **C001**（7.4V / 1/345） | 1 | 已到。只用于台面配置练习，**不装到手臂上** |
| 电源 | **3S 锂电 12.6V 直通**（已有） | — | 见下方电源方案 |

### 电源方案（C047 版）

C047 工作范围 **4~14V**，所以 **3S 锂电满电 12.6V 可以直通舵机总线，不需要降压**。

```
  Mac ──USB──▶ ESP32-S3      ← 5V 供电 + 串口日志，一根线两用
                 │
                 ├─ GPIO17 ─[1kΩ]─┐
                 ├─ GPIO16 ───────┤──▶ 总线 DATA
                 └─ GND ──────────┤
                                  │
 3S 锂电 12.6V ───────────────────┴──▶ 舵机总线（V+ / GND）
```

**ESP32 用电脑 USB 供电**，所以不需要 UBEC 了，电源链只剩"锂电直通舵机"这一路。

### 三条接线铁律

1. **必须共地**。USB 供电时 ESP32 的 GND = 电脑 USB 的 GND，
   **必须接到舵机总线的 GND（电池负极）**。不接的话半双工 TTL 没有共同参考电平，
   表现为扫描时有时通有时不通、回读乱码——最难查的一类故障。
   电池是浮地的，电脑地和电池负极短接无风险。
2. **只从总线引 GND 和 DATA，绝不引 V+**。ESP32 的 5V 脚由 USB 喂，
   灌进 12.6V 会瞬间烧。
3. **上电顺序：先 USB，后电池**。舵机先上电时 DATA 线被舵机驱动，
   会经 GPIO16/17 的保护二极管倒灌进 3.3V 轨，导致 ESP32 起不来 / 连不上 WiFi /
   烧录失败。关机时反过来。

> 脱机演示（不插电脑）时，把 USB 线插到 **5V 充电宝**上即可，日志走 WebSocket 照样能看。
> 一代那个 **UBEC 5V 留着当备选**——两个 5V 源**二选一，别同时接**。

对比一代：一代是 `12.6V → UBEC 降压 → 分电盒 → 5 路 MG996R`，
那几个降压和分电盒都是为了老舵机。**二代换成总线舵机后，这两样都不需要了**——
舵机直通锂电，菊花链一根线串到底。

**如果用墙上电源而不是电池**：需要 **12V 5A+**。
C047 单个堵转电流 **2.7A**，六个关节最坏情况 16.2A。
**别买 12V 2A**——连两个关节同时轻微堵转都扛不住，表现是"一动就重启 / 舵机集体复位"。
按 5A 起买，10A 更稳。（官方 BOM 默认给的是 **5V** 电源，那是配 7.4V 舵机用的，别照点。）

### ⚠️ C001 和 C047 不能混在一条总线上

同一根总线共享电源。**C001 上限 7.4V，接在 12.6V 的总线上会烧。**

所以那颗 C001 只做两件事：
1. 台面练手 —— 熟悉 `servo-tools/bench.py` 的整套流程（**用 5~7.4V**）
2. 以后当备件 / 单独测试件

**C047 到货后，C001 不要接进手臂的总线。**

好在两者**协议、寄存器、减速比（1/345）完全一样**，
台面上学到的每一步都能原样搬到 C047 上，只有电压和 ID 要重设。

### 如果以后想加 Leader

Leader 用的是**另一套 SKU**，别顺手再买 6 个 C047：

- 3 × 1/147 减速比（C046）
- 2 × 1/191 减速比（C044）
- 1 × 1/345 减速比（C001）
- 而且官方注明 **Leader 只能 7.4V**

加 Leader 的主要动机是模仿学习的数据采集——LeRobot 官方的 ACT / SmolVLA
标准流程就是 Leader-Follower 遥操作录演示。没有 Leader 的话，
要用手势控制或网页控制台自己当遥操作源、自己解决到 LeRobot Dataset 的格式对接。
这是偏离官方路线的做法，但可以作为一个创新点写进简历。

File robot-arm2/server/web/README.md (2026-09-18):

# 机械臂遥控页（Vue 3 + Vite）

机械臂网页遥控端的 Vue 3 重写版，替代原来的单文件 `public/control.html`。

---

## 技术栈

| | |
|---|---|
| 框架 | Vue 3.5（Composition API + `<script setup>`） |
| 构建 | Vite 8 |
| 组件 | 单文件组件（SFC），`<style scoped>` 样式隔离 |
| 状态 | `reactive` / `ref` / `defineModel` |
| 通信 | Fetch API，节流发送 |

---

## 目录结构

```
web/
├── index.html                     # SPA 入口
├── vite.config.js                 # 构建配置（输出到 ../public/control）
└── src/
    ├── main.js                    # 应用入口
    ├── style.css                  # 全局样式
    ├── App.vue                    # 主页面：布局 + 预设 + 组合子组件
    ├── components/
    │   └── ServoCard.vue          # 单个舵机控制卡片
    └── composables/
        └── useArmControl.js       # 控制逻辑（角度状态、节流、API 调用）
```

---

## 设计要点

### 1. 逻辑与视图分离

控制逻辑全在 `composables/useArmControl.js`，组件只管渲染。

**好处**：将来把 HTTP 换成 WebSocket、或接入手势输入时，组件一行都不用改。
这也是 Vue 3 Composition API 相比 Options API 最大的价值 —— **按功能组织代码，而不是按选项类型堆在一起**。

### 2. `defineModel()` 实现组件双向绑定

子组件 `ServoCard.vue` 里：

```js
const model = defineModel({ type: Number, required: true })
```

父组件直接写 `v-model` 就能双向绑定，子组件不需要知道父组件怎么存数据。
这是 Vue 3.4+ 的语法糖，等价于手写 `props` + `emits('update:modelValue')`。

### 3. 节流，避免打爆 ESP32

拖动滑块每秒会触发几十次事件。每次请求都会经服务器转发给 ESP32，
不节流的话舵机会收到大量冗余指令。

`useArmControl.js` 里做了 60ms 节流：**拖动过程中只保留最后一次，松手才真正发送**。
但按钮点击（精确跳转）走 `setAngleNow()`，不做节流 —— 用户点了就应该立刻响应。

### 4. 构建产物不入库

`vite.config.js` 把产物输出到 `../public/control`，由 Express 的 `express.static` 托管。
该目录已在 `.gitignore` 中排除，部署时需要先构建。

---

## 开发与构建

```bash
# 首次：安装依赖（前后端一起）
npm run setup

# 开发模式（热更新，API 请求自动代理到 :3000）
npm run dev:web

# 构建（产物输出到 ../public/control/）
npm run build

# 启动服务器
npm start
```

开发模式下 Vite 跑在 5173，`vite.config.js` 里配了代理：

```js
proxy: {
  '/set': 'http://localhost:3000',
  '/api': 'http://localhost:3000',
}
```

所以开发时不需要处理跨域。

---

## 部署

```bash
git pull
npm install
npm run build      # ← 别漏了这步，产物不入库
npm start
```

---

## 和手势模块的关系

两者是平级的客户端，都通过 HTTP 调同一个接口：

```
Vue 网页遥控 ──┐
               ├──HTTP /set?servo=i&angle=a──> Node 服务器 ──WebSocket──> ESP32
Python 手势 ───┘
```

详见 `gesture-control/README.md`。

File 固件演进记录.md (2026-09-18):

# 固件演进记录

记录每一版固件的用途、被取代的原因，以及项目在每个阶段解决的实际问题。

> 这份记录的价值在于：**它展示了技术方案是怎么一步步演化出来的**，
> 而不是一开始就设计好。每个版本都对应一个真实遇到的问题。

---

## 一、版本总览

固件分属两个阶段的目录：

- **`robot-arm 1/`** —— 第一代（2026-08-16 冻结快照）
- **`robot-arm2/`** —— 第二代（当前版本）

| 固件 | 位置 | 时期 | 定位 | 状态 |
|---|---|---|---|---|
| `servo-test/` | robot-arm 1 | 最早 | 基础遥控：softAP + PCA9685 + 网页滑块 | 🔵 已归档 |
| `servo-direct-test/` | robot-arm 1 | 08-15 | 故障排查：单舵机直驱，判断抖动来源 | 🔵 已归档 |
| `arm-5servo/` | robot-arm 1 | 08-15 | 备用方案：绕开 PCA9685 直驱 5 路 | 🔵 已归档 |
| `wifi-off-hold-test/` | robot-arm 1 | 09-02 | **决定性实验**：关 WiFi 验证抖动根因 | 🔵 已归档 |
| `arm-cloud/` | robot-arm 1 | 08-13<br>09-18 重写 | **云连接版**：STA + WebSocket + PCA9685 | 🔵 已归档 |
| `arm-bus-servo/` | **robot-arm2** | 09-18 | 总线舵机版：softAP + STS3215 | 🟡 待上机 |
| `arm-cloud-bus/` | **robot-arm2** | 09-18 | **合并版**：云连接 + 总线舵机 | 🟢 **当前主线** |
| `servo-direct/` | — | — | 已删除的历史版本 | ⚫ 见 git 历史 |
| `servo-test/servo-single.ino` | — | 最早 | 已删除：单舵机测试 | ⚫ 见 git 历史 |

> 📌 **为什么第一代的固件不再更新**：它们已被 `arm-cloud*` 系列取代
> （都实现了云连接，且 `arm-cloud-bus` 还解决了抖动问题）。
> 保留它们是为了记录技术演进 —— 面试时"为什么从 A 换到 B"比"我会用 B"更有说服力。

---

## 二、时间线

```
2026-08-11  ┌─ WiFi STA 模式连接手机热点
            │  从"ESP32 自建热点"迈出第一步，让它能连外部网络
            │
2026-08-13  ├─ 云服务器 WebSocket 中转 + 网页远程控制   ← 里程碑
            │  ESP32 主动连出，实现公网可控
            │  ⚠️ 此时 WiFi 密码被硬编码在固件里提交到了公开仓库
            │     （已于 09-18 从全部历史中清除）
            │
2026-08-15  ├─ 舵机信号/电源分离接线，新增直驱诊断代码
            │  发现抖动问题，开始排查
            │
2026-08-15  ├─ 删除直驱诊断代码 servo-direct
            │
2026-08-16  ├─ 产品官网（留言板/下载/PWA）+ WebSocket 设备鉴权
            │  加入 token 校验，防止伪造设备连接
            │
2026-09-02  ├─ 抖动诊断：关 WiFi 锁死测试
            │  ★ 决定性实验 —— 关掉 WiFi 后完全不抖，确诊为射频耦合
            │
2026-09-18  ├─ 手势识别控制 + 留言板接入 MySQL
            ├─ 总线舵机固件（STS3215）与升级文档
            ├─ 遥控页改用 Vue 3 + Vite 重写
            ├─ 接入 Swagger 接口文档
            ├─ 云连接版固件（从历史恢复并升级）
            │
2026-09-18  └─ 系统技术文档 + 根 README + 本演进记录
```

---

## 三、关键转折点

### 转折 1：从局域网到公网（08-13）

**问题**：ESP32 在局域网里，没有公网 IP，外面访问不进来。

**走过的路**：先试了 softAP 自建热点（`servo-test/`），只能局域网直连。

**最终方案**：让 ESP32 **主动连出去**，和服务器保持 WebSocket 长连接，服务器顺着这条连接把命令转发进来。

```
❌ 端口映射      —— 要路由器权限，且暴露内网
❌ 内网穿透      —— 要跑额外服务，免费版不稳
✅ 设备主动连出  —— 物联网设备的标准做法
```

### 转折 2：抖动问题（08-15 发现 → 09-02 确诊）

**现象**：5 个舵机静止锁定时小幅抽搐，**不同步**，空载也抖。

**排查**（逐步排除，最终锁定）：

| 怀疑对象 | 验证方法 | 结论 |
|---|---|---|
| PCA9685 | 拆掉改直驱，仍抖 | ❌ 排除 |
| 舵机个体 | 全部都会抖 | ❌ 排除 |
| 供电不足 | 5V 20A 余量充足，空载也抖 | ❌ 排除 |
| 机械虚位 | 空载也抖 | ❌ 排除 |
| **WiFi 射频** | **关掉 WiFi 烧录 → 完全不抖** | ✅ **确诊** |

**根因**：模拟舵机靠"量脉宽长度"决定角度，ESP32 的 2.4GHz 射频耦合进未屏蔽的信号线，让脉宽被撑长/削短几微秒，舵机当成一次角度变化。

**意外发现**：绕开 PCA9685 改直驱**反而更糟**——因为直驱把信号源搬到了射频源（ESP32）旁边，还把信号线加长了。

**解决思路**：
- 治标：信号线串 100Ω + 舵机端对地并小电容 + 星形接地（约 70–85% 成功率）
- **治本：换串行总线舵机** —— 数字协议带校验和，噪声要么被电平阈值滤掉、要么校验失败被丢弃，属于**协议层免疫**

### 转折 3：安全整改（09-18）

**问题**：排查时发现，早期固件把 **WiFi 密码明文硬编码**并提交到了**公开仓库**，在历史里存在了几个月。

**处理**：
1. 用 `git filter-repo` 从**全部提交历史**中清除（不只是删文件）
2. 凭据抽离到 `secrets.h`，加入 `.gitignore`
3. 提供 `secrets.h.example` 作为模板

**教训**：清除历史 ≠ 撤销泄露。凭据一旦公开过，**唯一可靠的止损是更换凭据本身**。

---

## 四、固件选型指南

现在手上有多个固件，按需求选：

| 你的情况 | 用哪个 |
|---|---|
| **要用云链路 + 总线舵机（主线）** | **`robot-arm2/arm-cloud-bus/`** |
| 单独验证总线舵机协议 | `robot-arm2/arm-bus-servo/`（带串口调试命令） |
| 要用云链路 + 现有 MG996R 舵机 | `robot-arm 1/arm-cloud/` |
| 只想台架测试舵机，不接服务器 | `robot-arm 1/servo-test/`（softAP + 网页直连） |
| 排查抖动 / 做对比实验 | `robot-arm 1/wifi-off-hold-test/`、`robot-arm 1/servo-direct-test/` |

---

## 五、云端固件的两代对比

`arm-cloud/` 和 `arm-cloud-bus/` 上层完全一样，只有底层驱动不同：

| | `arm-cloud/` | `arm-cloud-bus/` |
|---|---|---|
| 舵机类型 | 模拟 PWM（MG996R） | 总线舵机（STS3215） |
| 驱动方式 | I2C → PCA9685 → PWM | TTL 串口 → 直接控制 |
| 运动控制 | **软件插补**：主循环每 15ms 逐度推进 | **硬件平滑**：下发"目标+时间"，舵机自己走 |
| 多轴同步 | 逐个写寄存器 | **SYNC_WRITE** 一条指令广播 |
| 抗射频干扰 | 需要硬件滤波 | 协议层免疫 |
| 力反馈 | ❌ 不支持 | ✅ 可读电流/位置 |
| 供电 | 5V | **7.4V** |

**注意**：总线版不需要软件插补，代码反而更简单——这是一个典型的"选对架构，代码自然简化"的例子。

---

## 六、如何找回已删除的历史版本

```bash
# 列出所有历史上出现过的固件文件
git log --all --pretty=format: --name-only --diff-filter=A | grep '\.ino' | sort -u

# 查看某个文件在历史上的所有版本
git log --all --oneline -- <路径>

# 取出某个版本的内容
git show <提交哈希>:<文件路径>
```

> 建议：**不要删除旧固件**。它们是项目演进的证据，
> 面试时"你为什么从 A 方案换到 B 方案"比"我会用 B"更有说服力。

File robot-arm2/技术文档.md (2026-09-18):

# 六自由度机械臂 · 系统技术文档

一份从硬件到云端的完整技术说明，解释这个系统**由什么组成**、**怎么运作**、以及**每个技术选择背后的原因**。

---

# 一、系统总览

## 它是什么

一台 3D 打印的六自由度机械臂，可以通过网页远程控制，也能用手势识别驱动。

机械结构采用 **SO-ARM101** 开源设计（Hugging Face LeRobot 项目的官方硬件）。

**六个自由度**（从下到上，与舵机编号一致）：

| 编号 | 关节 | 作用 |
|---|---|---|
| 0 | 底座旋转 | 水平旋转 |
| 1 | 肩部 | 抬升/下降 |
| 2 | 肘部 | 俯仰 |
| 3 | 腕俯仰 | 调整末端角度 |
| 4 | 腕旋转 | 末端自转 |
| 5 | 夹爪 | 抓取/松开 |

## 四层架构

```
┌─────────────────────────────────────────────────────┐
│  应用层    Vue 3 网页遥控  │  Python 手势识别            │
└──────────────────────┬──────────────────────────────┘
                       │ HTTP
┌──────────────────────▼──────────────────────────────┐
│  云服务层   Node.js + Express + WebSocket 中转         │
│            MySQL 数据持久化  │  OpenAPI 接口文档         │
└──────────────────────┬──────────────────────────────┘
                       │ WebSocket 长连接
┌──────────────────────▼──────────────────────────────┐
│  嵌入式层   ESP32-S3 固件（C++ / Arduino）             │
└──────────────────────┬──────────────────────────────┘
                       │ I2C（当前）/ TTL 串口总线（升级后）
┌──────────────────────▼──────────────────────────────┐
│  硬件层     PCA9685 驱动板  │  舵机 × 5  │  3D 打印结构  │
│            UBEC 降压  │  锂电池  │  分电盒               │
└─────────────────────────────────────────────────────┘
```

---

# 二、一次完整的数据流

**以"在网页上把底座转到 45°"为例，追踪整条链路。**

### ① 用户拖动滑块

浏览器里的 Vue 组件 `ServoCard.vue` 收到 `input` 事件，通过 `defineModel()` 把新值同步给父组件。

### ② 前端节流

`useArmControl.js` 里的 `setAngle()` 做 **60ms 节流**——拖动时每秒触发几十次事件，每次都发请求会把 ESP32 打爆。节流后只发最后一次。

```js
fetch('/set?servo=0&angle=45')
```

### ③ HTTP 请求到达服务器

Express 路由 `app.get('/set')` 命中：

```js
const cmd = servo + ':' + angle;   // "0:45"
if (esp32) esp32.send(cmd);        // 通过 WebSocket 发出
else res.status(503)               // 设备不在线
```

**注意 503**：网页和手势模块都用这个状态码判断"机械臂是否在线"。

### ④ WebSocket 转发到 ESP32

ESP32 在局域网/内网，没有公网 IP。它在启动时就**主动连出来**，和服务器建立一条长连接并保持。服务器拿到浏览器命令后，顺着这条已有连接往回发。

### ⑤ 固件解析命令

```cpp
void onMessage(WStype_t type, uint8_t* payload, size_t length) {
  String msg = String((char*)payload);   // "0:45"
  int idx = msg.substring(0, colon).toInt();   // 0
  int tgt = msg.substring(colon + 1).toInt();  // 45
  target[idx] = tgt;                      // 只记目标值，不立即执行
}
```

### ⑥ 主循环分步推进

```cpp
void loop() {
  ws.loop();        // 保持通信，必须高频调用
  stepMotion();     // 每 15ms 推进一步
}
```

`stepMotion()` 遍历所有舵机，凡是当前值 ≠ 目标值的就 ±1 度。**五个舵机因此能并行运动**，而且 `loop()` 始终不阻塞。

### ⑦ 写入 PCA9685

```cpp
pwm.setPWM(CH[i], 0, angleToPWM(a));
```

这行代码**不是直接输出 PWM**，而是通过 **I2C 总线**把"目标脉宽"写进 PCA9685 的寄存器。

### ⑧ 舵机转动

PCA9685 收到寄存器值后，**用自己的晶振硬件产生 50Hz 的 PWM 波形**，持续输出，直到下次被改写。舵机内部的电位器检测当前角度，与脉宽对应的目标角度比较，驱动电机转到位。

### ⑨ 到位回报

所有舵机都到达目标后，固件把当前状态回传：

```
0:45,1:90,2:90,3:90,4:90
```

服务器日志打印出来，网页端可据此显示"已到位"。

---

# 三、硬件层

## 舵机

**模拟 PWM 舵机**（MG996R 类）：

| 参数 | 值 |
|---|---|
| 工作电压 | 4.8 – 7.2 V |
| 控制方式 | PWM，50Hz |
| 脉宽范围 | 0.5 – 2.5 ms 对应 0 – 180° |
| 堵转电流 | 约 1.5 A |

**工作原理**：舵机内部有电位器检测当前角度，控制电路把"脉宽长度"翻译成目标角度，两者比较后驱动电机转动，直到一致。所以它**只认脉宽**——脉宽被干扰改变几个微秒，舵机就会当成一次角度变化。

> ⚠️ 这正是本项目"抖动问题"的根源，详见第六节。

## 驱动板 PCA9685

**为什么需要它**：ESP32 的硬件 PWM（LEDC）通道数量有限，且用它直接驱动 5 路舵机会让信号线从 ESP32 一路拉到机械臂——线长、贴近天线。

PCA9685 是 **I2C 转 16 路 PWM** 的驱动芯片：

```
ESP32 ──I2C（2 根线）──> PCA9685 ──PWM（16 路）──> 舵机
```

**好处**：
- ESP32 只需 2 根线（SDA/SCL）就能控制 16 路
- PWM 由 PCA9685 **自己产生**，ESP32 不参与，不受其 WiFi 活动影响
- 可以把 PCA9685 放在**靠近舵机**的位置，缩短 PWM 信号线

## 供电

```
12.6V 锂电池 ──> UBEC 降压 5V ──> 2进12出分电盒 ──> 5 路舵机
                                                    └──> 一根地线回 ESP32 共地
```

**为什么要独立供电**：5 个舵机同时动作时峰值电流可达数安培。如果从 ESP32 取电，电压会被拉垮导致单片机复位。

**必须共地**：ESP32 和舵机电源的 GND 必须接在一起，否则 PWM 信号没有共同的参考电平。

---

# 四、嵌入式层

## ESP32-S3

- 双核 Xtensa LX7，240MHz
- 内置 **2.4GHz WiFi**（本项目用它的 STA 模式连路由器）
- 硬件外设：I2C、UART、LEDC(PWM) 等

## 固件的两种模式

| 模式 | 代表固件 | 特点 |
|---|---|---|
| **softAP 自建热点** | `servo-test.ino` | ESP32 自己开热点，浏览器直连它的 IP。简单，但**只能局域网** |
| **STA 连路由器 + WebSocket** | `arm-cloud.ino` | ESP32 主动连服务器，可**公网访问** |

## 非阻塞运动控制

**反面教材**（早期写法）：

```cpp
while (angles[idx] != tgt) {      // ❌ 阻塞
  angles[idx] += step;
  writeServo(idx, angles[idx]);
  delay(15);
}
```

问题有二：
1. `delay` 期间 `loop()` 卡死，**WebSocket 收不到新消息、心跳发不出去**，服务器会判定设备掉线
2. 多轴只能一个一个动

**正确写法**：

```cpp
void loop() {
  ws.loop();       // 通信优先
  stepMotion();    // 所有轴并行推进
}
```

## 通信健壮性

```cpp
ws.setReconnectInterval(5000);        // 断了自动重连
ws.enableHeartbeat(15000, 3000, 2);   // 心跳保活
```

**心跳为什么必要**：家用路由器和运营商的 NAT 会掐断长时间空闲的 TCP 连接。没有心跳的话，连接看着还在，实际已经死了，命令发不进去。

---

# 五、云服务层

## 为什么需要服务器中转

**核心矛盾**：ESP32 在局域网里，**没有公网 IP**。

三种解法对比：

| 方案 | 问题 |
|---|---|
| 端口映射 | 需要路由器管理权限，且暴露家庭内网 |
| 内网穿透（frp/ngrok） | 要额外跑一个服务，免费版不稳定 |
| **设备主动连出（本项目）** | ESP32 主动连服务器并保持长连接，服务器顺着这条连接往回发命令 |

第三种是**物联网设备的标准做法**——不需要公网 IP，不用改路由器。

## 技术栈

**Express**：提供 REST API 和静态站点托管

**ws 库**：WebSocket 服务端，与 Express 共用同一个 HTTP server

**设备鉴权**：ESP32 连接时必须在地址里带 token

```js
const token = url.searchParams.get('token');
if (token !== config.ESP32_TOKEN) {
  ws.close();   // 不对就断开
}
```

**为什么需要**：否则任何人只要知道服务器地址，就能伪造设备连接、劫持控制权。

## MySQL 数据持久化

留言板从 JSON 文件迁移到 MySQL：

| | JSON 文件 | MySQL |
|---|---|---|
| 并发 | 全量读写，有竞态 | 行级锁，并发安全 |
| 查询 | 全部读进内存 | 索引加速 |
| 关联 | 手工维护 | 外键约束 |

**两个具体优化**（详见 `server/DATABASE.md`）：

- **索引优化**：给 `created_at` 加索引后，列表查询扫描行数从 **49914 → 20**，耗时 **11.76ms → 0.30ms**
- **消除 N+1 查询**：列表接口从"1 条留言查 1 次回复"（1+N 次查询）改为用 `IN` 批量取回再内存归组（**固定 2 次**）

## 接口文档

**OpenAPI 3.0 + Swagger UI**，注解以 JSDoc 形式写在路由上方，文档与代码同步维护。

访问 `/api-docs` 可在线调试，`/api-docs.json` 可导入 Postman。

---

# 六、关键技术问题：抖动

这是本项目**最有价值的一段工程经历**。

## 现象

5 个舵机静止锁定时，全部有小幅抽搐，**不同步**。空载也抖。

## 排查过程（逐步排除）

| 怀疑对象 | 验证方法 | 结论 |
|---|---|---|
| PCA9685 板坏了 | 拆掉改直驱，仍抖 | ❌ 排除 |
| 个别舵机坏 | 全部都会抖 | ❌ 排除 |
| 供电不足 | 5V 20A 余量充足，空载也抖 | ❌ 排除 |
| 机械虚位 | 空载也抖 | ❌ 排除 |
| **WiFi 射频** | **关掉 WiFi 烧录 → 完全不抖** | ✅ **确诊** |

## 根因

**ESP32 的 2.4GHz WiFi 射频耦合进了那 5 根未屏蔽的信号线。**

模拟舵机靠"量脉宽长度"决定角度。射频毛刺叠上去，脉宽被撑长或削短几微秒，舵机就把它当成一次角度变化 → 抽搐。不同舵机耦合强度不同 → 看起来"异步"。

## 为什么直驱反而更糟

| | PCA9685 方案 | 直驱方案 |
|---|---|---|
| PWM 从哪来 | PCA 芯片自己产生 | ESP32 GPIO |
| 信号线起点 | 从 PCA 出发（**远离射频源**） | **从 ESP32 出发（就是射频源）** |
| 信号线长度 | 短 | 长 |

直驱把"信号源"搬到了射频源旁边，还顺手加长了天线。

## 两种解决思路

**思路 A：信号完整性层面压制**（治标）

- 每根信号线串 100Ω 电阻，磨圆陡边沿
- 每个舵机信号端对地并 1–4.7nF 电容，旁路射频
- 星形接地，信号线远离天线

成功率约 70–85%，需要反复调试。

**思路 B：换架构**（治本）

改用**串行总线舵机**（如 Feetech STS3215）：

```
传统舵机：  ──PWM 脉宽（模拟量）──>  舵机
总线舵机：  ──数字协议帧 + 校验和──>  舵机
```

总线舵机的指令是有帧格式的：

```
0xFF 0xFF ID LENGTH INSTRUCTION 参数... 校验和
```

噪声混进来，要么被数字电平阈值滤掉，要么**造成校验失败被舵机直接丢弃**——永远不会翻译成角度。

**这是协议层面的免疫，不是靠滤波压制。**

**附加收益**：总线舵机是闭环的，能回传当前位置和**电流**。电流 ≈ 力矩，于是可以做**力反馈**——夹爪抓握力度控制、碰撞检测、堵转保护。这是模拟舵机做不到的（它只有一根信号线进，什么都不回）。

---

# 七、应用层

## Vue 3 网页遥控

**技术栈**：Vue 3.5 + Vite 8 + 单文件组件

**目录结构**：

```
web/src/
├── App.vue                      主页面
├── components/ServoCard.vue     舵机卡片（可复用组件）
└── composables/useArmControl.js 控制逻辑
```

**设计要点**：

- **逻辑与视图分离** —— 控制逻辑全在 composable 里，组件只管渲染。将来换成 WebSocket 或接入手势输入，组件一行都不用改
- **`defineModel()` 双向绑定** —— 子组件不需要知道父组件怎么存数据
- **节流** —— 拖动只发最后一次，按钮点击不节流（保证即时响应）

## Python 手势识别

**技术栈**：MediaPipe + OpenCV

**流程**：摄像头 → 手部 21 个关键点 → 手指伸展判定 → 手势分类 → HTTP 命令

**核心算法**：判断手指是否伸直，常见做法是"指尖 y 坐标比指节小"，但**这要求手掌必须竖直朝上**，手一歪就判错。

本项目改用**距离比较**：

```
伸直 → 指尖伸得更远 → 指尖到掌心的距离 > 指节到掌心的距离
弯曲 → 指尖收回掌心 → 距离反而更小
```

这个方法与**手掌朝向、旋转、离镜头远近都无关**，稳得多。

**两种模式**：
- 指令模式：固定手势触发固定动作（张开/握拳/数字…）
- 跟随模式：手掌位置实时映射到底座和大臂角度

---

# 八、技术栈总览

| 层面 | 技术 |
|---|---|
| **嵌入式** | C++ / Arduino、ESP32-S3、I2C、PWM、TTL 串口协议、WebSocket 客户端 |
| **后端** | Node.js、Express、ws（WebSocket）、MySQL、连接池、参数化查询 |
| **前端** | Vue 3（Composition API / SFC）、Vite、HTML/CSS/JS、PWA |
| **AI** | Python、MediaPipe、OpenCV |
| **数据库** | MySQL、索引优化、EXPLAIN 分析、N+1 优化、外键约束 |
| **接口文档** | OpenAPI 3.0、Swagger UI |
| **工程工具** | Git、uv、npm、Arduino CLI、MySQL |
| **部署** | Linux、Nginx、SSL |

---

# 九、项目演进时间线

```
1. 基础遥控        ESP32 softAP + PCA9685 + 网页滑块
2. 云化改造        ESP32 改 STA 模式 + WebSocket 客户端 → 公网可控
3. 发现抖动        5 个舵机静止时小幅抽搐
4. 排除法定位      逐个排除硬件嫌疑，最终确诊为 WiFi 射频耦合
5. 整改变压        信号侧加串阻/电容/星形接地（压制，治标）
6. 架构升级        换总线舵机（协议层免疫，治本）+ 力反馈
7. 功能扩展        手势识别 + MySQL + Vue 3 重写 + Swagger 文档
```

---

# 十、可延伸方向

| 方向 | 说明 |
|---|---|
| **力反馈** | 读取总线舵机的电流，实现夹爪力度控制、碰撞检测 |
| **逆运动学** | 给定末端坐标，反解各关节角度，实现"告诉我位置而不是角度" |
| **轨迹规划** | 直线插补、圆弧插补，让末端走平滑路径 |
| **视觉抓取** | 摄像头识别物体位置 → 逆运动学解算 → 自动抓取 |
| **多机协同** | 服务器已支持设备鉴权，扩展成多设备管理即可 |

---

## 相关文档

| 文档 | 内容 |
|---|---|
| [`server/README.md`](server/README.md) | 服务器架构、部署、接口速查 |
| [`server/DATABASE.md`](server/DATABASE.md) | 数据库设计与 SQL 优化实证 |
| [`server/web/README.md`](server/web/README.md) | Vue 前端设计说明 |
| [`gesture-control/README.md`](gesture-control/README.md) | 手势识别模块 |
| [`arm-cloud-bus/`](arm-cloud-bus/) | 云连接 + 总线舵机固件 |
| [`arm-bus-servo/README.md`](arm-bus-servo/README.md) | 总线舵机升级指南 |
| [抖动诊断结论.md](../robot-arm%201/wifi-off-hold-test/抖动诊断结论.md) | 抖动问题的诊断报告（第一代归档） |

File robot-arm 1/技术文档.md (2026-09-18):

# 第一代机械臂 · 系统技术文档

记录 2026-08-11 ~ 08-16 这一阶段的系统构成、技术决策，
以及**那段持续半个月的抖动排查过程**。

> 第二代文档见 [`../robot-arm2/技术文档.md`](../robot-arm2/技术文档.md)

---

# 一、这一代做了什么

**目标**：让机械臂能被远程控制。

**成果**：从"局域网直连"走到"公网可远程控制"，并完成了配套官网。

```
局域网直连 ────────────> 公网远程控制
（ESP32 自建热点）        （ESP32 主动连出 + 云服务器中转）
```

| 时间 | 提交 | 内容 |
|---|---|---|
| 08-11 | `3e10e33` | WiFi STA 模式连接手机热点 |
| 08-13 | `080e956` | **云服务器 WebSocket 中转 + 网页远程控制** ← 里程碑 |
| 08-15 | `9169b6e` | 舵机信号/电源分离接线，新增直驱诊断代码 |
| 08-15 | `3d1aec4` | 清理诊断代码 |
| 08-16 | `ae99c60` | 产品官网（留言板/下载/PWA）+ WebSocket 设备鉴权 |

---

# 二、系统架构

```
┌──────────────────────────────────────────────┐
│  浏览器（原生 HTML/CSS/JS，PWA）                │
└────────────────────┬─────────────────────────┘
                     │ HTTP
┌────────────────────▼─────────────────────────┐
│  Node.js + Express 服务器（阿里云）             │
│  WebSocket 中转  │  token 设备鉴权  │  JSON 存储 │
└────────────────────┬─────────────────────────┘
                     │ WebSocket 长连接
┌────────────────────▼─────────────────────────┐
│  ESP32-S3 固件（WiFi STA 模式，主动连出）       │
└────────────────────┬─────────────────────────┘
                     │ I2C
┌────────────────────▼─────────────────────────┐
│  PCA9685 ── PWM ──> 5 个模拟舵机（MG996R）     │
│  供电：12.6V 锂电 → UBEC 5V 20A → 分电盒       │
└──────────────────────────────────────────────┘
```

---

# 三、关键技术决策

## 决策 1：为什么用 PCA9685 而不是 ESP32 直驱

ESP32 的硬件 PWM 通道有限，且直接驱动会让 5 根信号线从 ESP32 一路拉到机械臂——
线长、贴近天线。PCA9685 把 PWM 的产生挪到了靠近舵机的位置，
ESP32 只需 2 根 I2C 线。

> 这个决策在后来排查抖动时被验证是对的（见第四节"绕开 PCA9685 反而更糟"）。

## 决策 2：为什么让 ESP32 主动连出

**问题**：ESP32 在局域网里，没有公网 IP，外面访问不进来。

| 方案 | 问题 |
|---|---|
| 端口映射 | 需要路由器管理权限，且暴露家庭内网 |
| 内网穿透（frp/ngrok） | 要额外跑服务，免费版不稳定 |
| **设备主动连出** | ESP32 主动连服务器并保持长连接，服务器顺着这条连接往回发命令 |

选了第三种——这是**物联网设备的标准做法**。

## 决策 3：为什么加 token 鉴权

服务器地址是公开的。如果不校验，任何人只要知道地址，就能伪造设备连接、劫持控制权。

```js
const token = url.searchParams.get('token');
if (token !== config.ESP32_TOKEN) ws.close();
```

---

# 四、★ 排查过程记录

**这是这一代最有价值的部分。**

## 4.1 问题的发现（08-15）

系统跑通后，发现一个现象：

> **5 个舵机静止锁定时，全部有小幅抽搐，不同步。**
> **不承重（空载）也会抖。**

于是开始了排查。当时创建了 `servo-direct/servo-direct.ino`（单舵机直驱测试）
作为诊断工具。

## 4.2 排查思路

舵机抖动可能的原因有几类：

```
          ┌── 舵机自身：电位器磨损、死区过大
抖动原因 ─┼── 驱动电路：PCA9685 输出不稳
          ├── 供电：电压跌落、纹波过大
          ├── 机械：齿轮虚位、负载
          └── 信号：外部干扰耦合进信号线
```

思路是**逐个排除**：每次只改变一个变量，看抖动是否消失。

## 4.3 逐步排除

| 怀疑对象 | 验证方法 | 结果 | 结论 |
|---|---|---|---|
| PCA9685 板故障 | 拆掉 PCA，改 ESP32 直驱 | **仍然抖** | ❌ 排除 |
| 个别舵机损坏 | 观察是否只有特定舵机抖 | **全部都会抖** | ❌ 排除"个别坏件" |
| 供电不足 | 查电源余量；观察空载是否还抖 | 5V 20A 余量充足，**空载也抖** | ❌ 排除欠压振荡 |
| 机械虚位 | 空载测试 | **空载也抖** | ❌ 排除机械问题 |
| **外部干扰** | 隔离干扰源 | **不抖了** | ✅ **确诊** |

## 4.4 一个反直觉的发现

排查中把 PCA9685 拆掉、改成 ESP32 直接驱动舵机——**结果抖动反而更严重了**。

这个"失败"的尝试其实很有价值，它反向验证了干扰的来源：

| | PCA9685 方案 | 直驱方案 |
|---|---|---|
| PWM 从哪来 | PCA 芯片自己产生 | ESP32 的 GPIO |
| 信号线起点 | 从 PCA 出发（**离射频源远**） | **从 ESP32 出发（就是射频源本身）** |
| 信号线长度 | 短 | 长（要从 ESP32 拉到机械臂） |
| 5 根线的关系 | 从 PCA 出来 | 从**相邻 GPIO** 出来，天然并排 |

**直驱把"信号源"搬到了干扰源旁边，还顺手把天线加长了。**

## 4.5 决定性实验（09-02）

前面的排除都指向"外部干扰"，但需要确证。做了这个实验：

> **烧录 `wifi-off-hold-test.ino`：不开 WiFi，纯硬件锁死 5 个舵机。**

```
结果：完全不抖。
```

**确诊**：ESP32 的 **2.4GHz WiFi 射频**（含地弹）耦合进了未屏蔽的信号线。

### 为什么会导致抽搐

模拟舵机靠**量脉宽长度**决定角度（0.5–2.5ms 对应 0–180°）。

静止时固件不再写 PWM，信号本是一条恒定脉宽。但 WiFi 发包瞬间的射频毛刺
耦合进信号线，让脉宽被撑长或削短几微秒——**舵机就把它当成一次角度变化**。

不同舵机、不同时刻的耦合强度不同 → 看起来"异步、小幅"。

## 4.6 当时的整改尝试

在这一代里做了电源侧的整改：

- 在 2进12出分电盒输入端并联 **1000µF 电解电容**
- 舵机信号/电源走线分离

**结论：没有解决问题。**

原因很明确——**电源电容滤的是电源纹波和瞬态压降，而干扰走的是
"空气 → 信号线"这条路径，根本不经过电源线。**

这是一个重要的认知：**滤错了对象，再大的电容也没用。**

正确的做法应该是在**信号线两端**处理：
- PCA9685 输出端串 100Ω（磨圆陡边沿）
- 舵机信号输入端对地并 1–4.7nF（旁路射频）

---

# 五、这一代的局限

排查到最后，得出的核心结论是：

> **这是模拟舵机的架构性矛盾，不是接线问题。**

模拟舵机只能靠脉宽传递角度，任何叠加在信号线上的噪声都会被"翻译"成角度。
加电容电阻是在**信号完整性层面打消耗战**，成功率有限。

| 遗留问题 | 说明 |
|---|---|
| **抖动** | 根因已定位，但未根治 |
| 数据存储 | JSON 文件，全量读写、有竞态 |
| 前端 | 原生 JS 单文件，难维护 |
| 接口文档 | 无 |
| 力反馈 | 模拟舵机不支持 |

**这些正是第二代要解决的。**

---

# 六、技术栈

| 层面 | 技术 |
|---|---|
| 嵌入式 | C++ / Arduino、ESP32-S3、I2C、PWM、WebSocket 客户端 |
| 后端 | Node.js、Express、ws（WebSocket） |
| 前端 | 原生 HTML / CSS / JavaScript、PWA |
| 存储 | JSON 文件 |
| 部署 | 阿里云服务器 |

---

# 七、与第二代的对比

| | 第一代 | 第二代 |
|---|---|---|
| 舵机驱动 | PCA9685 + 模拟舵机 | **总线舵机（协议层免疫干扰）** |
| 数据存储 | JSON 文件 | **MySQL（含索引优化）** |
| 前端 | 原生 JS | **Vue 3 + Vite** |
| 接口文档 | 无 | **OpenAPI / Swagger** |
| AI 功能 | 无 | **手势识别** |
| 力反馈 | 不支持 | **支持**（读电流） |
| 抖动 | ❌ 未解决 | ✅ 根治 |

> 第二代完整文档：[`../robot-arm2/技术文档.md`](../robot-arm2/技术文档.md)

---

# 八、本目录文档索引

| 文档 | 内容 |
|---|---|
| [`wifi-off-hold-test/抖动诊断结论.md`](wifi-off-hold-test/抖动诊断结论.md) | 抖动问题的诊断报告（决定性实验） |
| [`arm-cloud/README.md`](arm-cloud/README.md) | 云连接固件配置与测试 |
| [`servo-test/机械臂课件.md`](servo-test/机械臂课件.md) | 舵机基础知识 |
| [`../固件演进记录.md`](../固件演进记录.md) | 每版固件的定位与演进 |

---

# 九、这段经历的价值

排查本身比"跑通系统"更有含金量：

1. **完整的科学方法**：假设 → 设计实验 → 逐个排除 → 定位根因
2. **接受"失败"的尝试**：直驱方案失败了，但它反向验证了干扰来源
3. **识别出架构性问题**：没有停留在"多加几个电容试试"，而是判断出
   这是模拟舵机的原理性缺陷
4. **知道什么时候该换方案**：在信号完整性层面继续投入是边际递减的，
   换架构才是正解

> 面试时这段比"我会用什么框架"更有说服力——它体现的是**工程判断力**。

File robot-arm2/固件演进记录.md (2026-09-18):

# 固件演进记录

记录每一版固件的用途、被取代的原因，以及项目在每个阶段解决的实际问题。

> 这份记录的价值在于：**它展示了技术方案是怎么一步步演化出来的**，
> 而不是一开始就设计好。每个版本都对应一个真实遇到的问题。

---

## 一、版本总览

| 固件 | 时期 | 定位 | 状态 |
|---|---|---|---|
| `servo-test/` | 最早 | 基础遥控：softAP + PCA9685 + 网页滑块 | 🔵 台架保留 |
| `servo-direct-test/` | 08-15 | 故障排查：单舵机直驱，判断抖动来源 | 🔵 诊断工具 |
| `arm-5servo/` | 08-15 | 备用方案：绕开 PCA9685 直驱 5 路 | 🔵 台架保留 |
| `wifi-off-hold-test/` | 09-02 | **决定性实验**：关 WiFi 验证抖动根因 | 🔵 诊断工具 |
| `arm-cloud/` | 08-13<br>09-18 重写 | **云连接版**：STA + WebSocket + PCA9685 | 🟢 当前可用 |
| `arm-bus-servo/` | 09-18 | 总线舵机版：softAP + STS3215 | 🟡 待上机 |
| `arm-cloud-bus/` | 09-18 | **合并版**：云连接 + 总线舵机 | 🟡 待上机 |
| `servo-direct/` | — | 已删除的历史版本 | ⚫ 见 git 历史 |
| `servo-test/servo-single.ino` | 最早 | 已删除：单舵机测试 | ⚫ 见 git 历史 |

---

## 二、时间线

```
2026-08-11  ┌─ WiFi STA 模式连接手机热点
            │  从"ESP32 自建热点"迈出第一步，让它能连外部网络
            │
2026-08-13  ├─ 云服务器 WebSocket 中转 + 网页远程控制   ← 里程碑
            │  ESP32 主动连出，实现公网可控
            │  ⚠️ 此时 WiFi 密码被硬编码在固件里提交到了公开仓库
            │     （已于 09-18 从全部历史中清除）
            │
2026-08-15  ├─ 舵机信号/电源分离接线，新增直驱诊断代码
            │  发现抖动问题，开始排查
            │
2026-08-15  ├─ 删除直驱诊断代码 servo-direct
            │
2026-08-16  ├─ 产品官网（留言板/下载/PWA）+ WebSocket 设备鉴权
            │  加入 token 校验，防止伪造设备连接
            │
2026-09-02  ├─ 抖动诊断：关 WiFi 锁死测试
            │  ★ 决定性实验 —— 关掉 WiFi 后完全不抖，确诊为射频耦合
            │
2026-09-18  ├─ 手势识别控制 + 留言板接入 MySQL
            ├─ 总线舵机固件（STS3215）与升级文档
            ├─ 遥控页改用 Vue 3 + Vite 重写
            ├─ 接入 Swagger 接口文档
            ├─ 云连接版固件（从历史恢复并升级）
            │
2026-09-18  └─ 系统技术文档 + 根 README + 本演进记录
```

---

## 三、关键转折点

### 转折 1：从局域网到公网（08-13）

**问题**：ESP32 在局域网里，没有公网 IP，外面访问不进来。

**走过的路**：先试了 softAP 自建热点（`servo-test/`），只能局域网直连。

**最终方案**：让 ESP32 **主动连出去**，和服务器保持 WebSocket 长连接，服务器顺着这条连接把命令转发进来。

```
❌ 端口映射      —— 要路由器权限，且暴露内网
❌ 内网穿透      —— 要跑额外服务，免费版不稳
✅ 设备主动连出  —— 物联网设备的标准做法
```

### 转折 2：抖动问题（08-15 发现 → 09-02 确诊）

**现象**：5 个舵机静止锁定时小幅抽搐，**不同步**，空载也抖。

**排查**（逐步排除，最终锁定）：

| 怀疑对象 | 验证方法 | 结论 |
|---|---|---|
| PCA9685 | 拆掉改直驱，仍抖 | ❌ 排除 |
| 舵机个体 | 全部都会抖 | ❌ 排除 |
| 供电不足 | 5V 20A 余量充足，空载也抖 | ❌ 排除 |
| 机械虚位 | 空载也抖 | ❌ 排除 |
| **WiFi 射频** | **关掉 WiFi 烧录 → 完全不抖** | ✅ **确诊** |

**根因**：模拟舵机靠"量脉宽长度"决定角度，ESP32 的 2.4GHz 射频耦合进未屏蔽的信号线，让脉宽被撑长/削短几微秒，舵机当成一次角度变化。

**意外发现**：绕开 PCA9685 改直驱**反而更糟**——因为直驱把信号源搬到了射频源（ESP32）旁边，还把信号线加长了。

**解决思路**：
- 治标：信号线串 100Ω + 舵机端对地并小电容 + 星形接地（约 70–85% 成功率）
- **治本：换串行总线舵机** —— 数字协议带校验和，噪声要么被电平阈值滤掉、要么校验失败被丢弃，属于**协议层免疫**

### 转折 3：安全整改（09-18）

**问题**：排查时发现，早期固件把 **WiFi 密码明文硬编码**并提交到了**公开仓库**，在历史里存在了几个月。

**处理**：
1. 用 `git filter-repo` 从**全部提交历史**中清除（不只是删文件）
2. 凭据抽离到 `secrets.h`，加入 `.gitignore`
3. 提供 `secrets.h.example` 作为模板

**教训**：清除历史 ≠ 撤销泄露。凭据一旦公开过，**唯一可靠的止损是更换凭据本身**。

---

## 四、固件选型指南

现在手上有多个固件，按需求选：

| 你的情况 | 用哪个 |
|---|---|
| 只想台架测试舵机，不接服务器 | `servo-test/`（softAP + 网页直连） |
| 要用云链路 + 现有 MG996R 舵机 | **`arm-cloud/`** |
| 要用云链路 + 已换总线舵机 | **`arm-cloud-bus/`** |
| 单独验证总线舵机协议 | `arm-bus-servo/`（带串口调试命令） |
| 排查抖动 / 做对比实验 | `wifi-off-hold-test/`、`servo-direct-test/` |

---

## 五、云端固件的两代对比

`arm-cloud/` 和 `arm-cloud-bus/` 上层完全一样，只有底层驱动不同：

| | `arm-cloud/` | `arm-cloud-bus/` |
|---|---|---|
| 舵机类型 | 模拟 PWM（MG996R） | 总线舵机（STS3215） |
| 驱动方式 | I2C → PCA9685 → PWM | TTL 串口 → 直接控制 |
| 运动控制 | **软件插补**：主循环每 15ms 逐度推进 | **硬件平滑**：下发"目标+时间"，舵机自己走 |
| 多轴同步 | 逐个写寄存器 | **SYNC_WRITE** 一条指令广播 |
| 抗射频干扰 | 需要硬件滤波 | 协议层免疫 |
| 力反馈 | ❌ 不支持 | ✅ 可读电流/位置 |
| 供电 | 5V | **7.4V** |

**注意**：总线版不需要软件插补，代码反而更简单——这是一个典型的"选对架构，代码自然简化"的例子。

---

## 六、如何找回已删除的历史版本

```bash
# 列出所有历史上出现过的固件文件
git log --all --pretty=format: --name-only --diff-filter=A | grep '\.ino' | sort -u

# 查看某个文件在历史上的所有版本
git log --all --oneline -- <路径>

# 取出某个版本的内容
git show <提交哈希>:<文件路径>
```

> 建议：**不要删除旧固件**。它们是项目演进的证据，
> 面试时"你为什么从 A 方案换到 B 方案"比"我会用 B"更有说服力。

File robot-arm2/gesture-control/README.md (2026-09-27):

# 手势控制机械臂

用摄像头识别手势，实时控制 6 自由度机械臂。

```
摄像头 → MediaPipe 手部关键点 → 手势判定 → HTTP → Node 服务器 → WebSocket → ESP32 → 舵机
```

手势模块只是**另一个客户端**，和网页遥控平级。现有服务器一行都不用改。

---

## 快速开始

```bash
cd gesture-control
uv run smoke_test.py        # 先自检：环境、模型、摄像头、服务器
uv run gesture_control.py   # 启动
```

首次运行 macOS 会弹窗申请摄像头权限，**点「允许」**。
如果没弹窗或误点了拒绝：系统设置 → 隐私与安全性 → 摄像头 → 勾选你的终端（Terminal / iTerm）。

### 常用参数

```bash
uv run gesture_control.py --dry-run              # 只识别，不发命令（不接机械臂也能调）
uv run gesture_control.py --url http://192.168.1.5:3000   # 连别的服务器
uv run gesture_control.py --camera 1             # 换摄像头
uv run gesture_control.py --no-window            # 不弹预览窗
```

### ⚠️ 控制需要登录（用户名 + 密码）

服务器要求登录后才能控制机械臂（防止陌生人乱动）。**两个字段都要给**：

```bash
# 方式一：环境变量（推荐，不留在命令历史里）
ARM_USERNAME=你的用户名 ARM_PASSWORD=你的密码 uv run gesture_control.py

# 方式二：命令行参数
uv run gesture_control.py --username 你的用户名 --password 你的密码
```

> 客户端先调 `/api/login` 换一个 token，之后所有 `/set` 请求自动带上。
> token 过期时会自动重新登录，不用手动处理。
>
> **只给密码不给用户名会一律 401，而且报的是「用户名或密码不对」** ——
> 服务端 `accounts.login(username, password)` 两个字段都要，缺用户名时
> 拿 `undefined` 去查，结果就是「查无此人」，错误信息看不出缺的是哪个。
> 症状很有迷惑性：画面照样有手骨架、照样报识别到的手势，机械臂就是不动。

### 快捷键

| 键 | 作用 |
|---|---|
| `q` | 退出 |
| `m` | 切换「指令模式 / 跟随模式」 |
| `r` | 全部回中 |
| `d` | 开/关调试输出 |

---

## 两种模式

> **当前模式看窗口顶部那条横幅**：🟩 绿色 = 指令模式，🟦 蓝色 = 跟随模式，
> 窗口标题栏也会跟着变（被挡住或缩进 Dock 里时看标题）。按 `m` 切换。

### 指令模式
固定手势触发固定动作，手势需**连续稳定 5 帧**才触发（防止手在过渡姿势时乱动）：

| 手势 | 动作 |
|---|---|
| ✋ 张开 | 夹爪张开 |
| ✊ 握拳 | 夹爪闭合 |
| ☝️ 数字1 | 全部回中 |
| ✌️ 剪刀手 | 预备姿态 |
| 数字3 | 抓取姿态 |
| 数字4 | 放下姿态 |

### 跟随模式
手掌在画面里的位置实时映射：
- 手掌 **左右** → 底座旋转
- 手掌 **上下** → 肩部俯仰

---

## 项目结构

```
gesture-control/
├── gestures.py          # 手势判定逻辑（纯计算，无外部依赖，可单测）
├── arm_client.py        # 与机械臂服务器通信（HTTP）
├── gesture_control.py   # 主程序：摄像头循环 + 模式处理 + 界面
├── smoke_test.py        # 冒烟测试：一键自检环境
└── tests/
    └── test_gestures.py # 单元测试（14 个用例）
```

**分层的意义**：`gestures.py` 不 import mediapipe、不碰摄像头、不发请求，
所以能脱离硬件单元测试；以后想换成 YOLO 或别的模型，也只需替换主程序里的检测部分。

```bash
uv run python -m unittest discover tests -v
```

---

## 三个技术细节

### 1. 手指伸直的判定方法

常见做法是「指尖 y 坐标比指节小就算伸直」——但这**要求手掌必须竖直朝上**，
手一歪就判错。

本项目比较的是**指尖到掌心的距离**和**近端指节到掌心的距离**：

```
伸直 → 指尖伸得更远 → 距离更大
弯曲 → 指尖收回掌心 → 距离反而更小
```

这个方法与手掌朝向、旋转、离镜头远近**都无关**。
测试 `test_orientation_independent` 专门验证了这一点：把整只手旋转 90°，结果不变。

顺带的好处：判定不用左右手信息，所以画面可以放心做镜像翻转（自拍视角）。

### 2. 为什么锁 MediaPipe 0.10.x + Python 3.12

MediaPipe **1.0.x 在 macOS 上初始化即崩溃**：

```
Check failed: service_ Service is unavailable.
  -[DrishtiMetalHelper initWithCalculatorContext:]
```

这是它 GPU（Metal）后端的问题，**强制 CPU delegate 也绕不过**。
所以退回成熟的 0.10.21；而 0.10.x 只支持到 Python 3.12，故用 uv 固定 3.12。

> 依赖版本已写死在 `pyproject.toml`，`uv sync` 会自动装对，不用手动处理。

### 3. 界面上的中文为什么不用 `cv2.putText`

OpenCV 自带的 Hershey 字体**只有 ASCII**，`cv2.putText` 画中文会退化成问号——
而且是**每个 UTF-8 字节一个**问号：

```
cv2.putText('模式: 指令  (m 切换)')   →   ??????: ??????  (m ??????)
```

叠加层整行都是中文，所以这个坑的后果是**整个界面没一个字能看**，
偏偏程序本身运行完全正常，很容易以为是"识别没出来"。

现在中文一律用 PIL + 系统中文字体（苹方）渲染成小图块，再按 alpha 贴回画面，
并按「文字+字号+颜色」缓存——这几行字每帧都长一样，没必要每帧重排。

---

## 接到真实的机械臂

手势模块只依赖服务器的 `/set` 接口：

```
GET /set?servo=<0-5>&angle=<0-180>
```

（0=底座 1=肩 2=肘 3=腕俯仰 4=腕旋转 5=夹爪）

1. 启动服务器：`cd ../server && npm start`
2. 确认 ESP32 已连上（服务器日志会打印「ESP32 认证通过」）
3. `uv run gesture_control.py`

服务器没开也能用 `--dry-run` 单独调试识别效果。

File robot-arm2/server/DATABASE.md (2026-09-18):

# 留言板数据库（MySQL）

原本留言存在 `server/data/messages.json` 里（整个数组读进内存，每次改动全量回写）。
现在改为 MySQL，本文档说明设计思路和用法。

---

## 一、快速开始

```bash
# 1. 确保 MySQL 在跑
brew services start mysql

# 2. 建库建表建账号（首次执行一次即可）
mysql -u root < schema.sql

# 3. 装依赖并启动
npm install
npm start
```

启动时会先探测数据库连接，连不上会直接报错退出，不会等到第一个请求才发现。

---

## 二、表结构设计

```
messages                          replies
┌────────────────────┐            ┌────────────────────┐
│ id      BIGINT  PK │◄──────┐    │ id         BIGINT PK│
│ nickname VARCHAR(50)│       └────│ message_id BIGINT FK│
│ content  VARCHAR(500)│          │ content    VARCHAR(500)│
│ created_at DATETIME(3)│         │ created_at DATETIME(3)│
│  KEY idx_created_at  │          │  KEY idx_message_id    │
└────────────────────┘            └────────────────────┘
                                         │
                    外键 ON DELETE CASCADE：删留言自动删掉它的回复
```

### 几个刻意的选择

| 决定 | 原因 |
|---|---|
| 回复单独建表，不塞进消息行 | 符合第一范式。塞 JSON 数组进一列的话，没法按回复查询、没法分页、也没法加约束 |
| `ON DELETE CASCADE` | 删留言时自动清理回复，数据库层面保证不留孤儿数据 |
| 字符集 `utf8mb4` | 支持完整 Unicode（含 emoji）。`utf8` 是阉割版，存不了 4 字节字符 |
| `DATETIME(3)` 而非 `TIMESTAMP` | 毫秒精度；且 `TIMESTAMP` 有 2038 年上限 |
| 存储引擎 `InnoDB` | 支持事务和外键（MyISAM 都不支持） |

### 索引

| 索引 | 服务于 |
|---|---|
| `messages.idx_created_at (created_at DESC)` | 列表页固定按时间倒序，直接顺着索引读，不用排序 |
| `replies.idx_message_id (message_id)` | 按留言查回复；外键列也必须有索引，否则删留言会全表扫 |

---

## 三、SQL 优化：实证

```bash
npm run explain
```

脚本会建 5 万行数据，对比加索引前后的执行计划和实测耗时。
全程只操作 `robot_arm_demo` 演示库，跑完自动删表，**不碰业务数据**。

实测结果：

| | 扫描行数 | 耗时 | Extra |
|---|---|---|---|
| 优化前 | 49914 | 11.76 ms | `Using filesort` |
| 优化后 | **20** | **0.30 ms** | `(空)` |

**扫描行数减少 99.96%，耗时快 39 倍。**

### 两个坑（都踩过）

**1. `ANALYZE TABLE` 不能省。**
批量插入后如果不更新统计信息，优化器没有依据，实测会**放弃索引去全表扫描**。
写完数据一定要 `ANALYZE TABLE`。

**2. MySQL 8.0.16+ 的 EXPLAIN 默认是树形格式。**
直接 `EXPLAIN` 返回的列名叫 `EXPLAIN`，拿到的是这种字符串：

```
-> Limit: 20 row(s)  (cost=2000 rows=20)
    -> Sort: t1.a DESC  (cost=2000 rows=20000)
        -> Table scan on t1  (cost=2000 rows=20000)
```

要经典的表格输出必须显式写 `EXPLAIN FORMAT=TRADITIONAL`。

---

## 四、另一个优化：消除 N+1 查询

列表接口要返回「每条留言 + 它的回复」，最容易写成这样：

```js
// ❌ N+1：30 条留言 = 1 + 30 = 31 次查询
const [messages] = await pool.query('SELECT * FROM messages ORDER BY created_at DESC');
for (const m of messages) {
  const [replies] = await pool.query('SELECT * FROM replies WHERE message_id = ?', [m.id]);
  m.replies = replies;
}
```

留言越多，查询次数线性增长。改成两条查询：

```js
// ✅ 固定 2 次查询，和留言条数无关
const [messages] = await pool.query('SELECT ... FROM messages ORDER BY created_at DESC');
const ids = messages.map(m => m.id);
const [replies] = await pool.query('SELECT ... FROM replies WHERE message_id IN (?)', [ids]);
// 然后在内存里按 message_id 归组
```

见 `store.js` 的 `list()`。

---

## 五、安全上的考虑

- **最小权限**：应用账号 `arm_app` 只有业务库的 `SELECT/INSERT/UPDATE/DELETE`，
  **没有 DROP/ALTER**。演示库另开一个 `robot_arm_demo` 放开权限。
- **全程参数化查询**：所有用户输入都走 `?` 占位符，杜绝 SQL 注入。
- **密码走环境变量**：`config.js` 里的是本地开发默认值，部署时必须用
  `DB_PASSWORD` / `ADMIN_PASSWORD` 覆盖，不要把生产密码写进代码。

---

## 六、从旧数据迁移

如果你之前用 JSON 文件存过留言：

```bash
npm run migrate
```

按原 id 导入（`INSERT IGNORE`，可重复执行不会重复插入），原文件保留不删。

---

## 文件一览

| 文件 | 作用 |
|---|---|
| `schema.sql` | 建库、建表、建账号，一条命令搞定 |
| `db.js` | MySQL 连接池 + 启动探活 |
| `store.js` | 数据访问层（对外接口和 JSON 版完全一致） |
| `migrate.js` | 旧 JSON 数据迁移 |
| `explain-demo.js` | SQL 优化实证（EXPLAIN + 压测） |

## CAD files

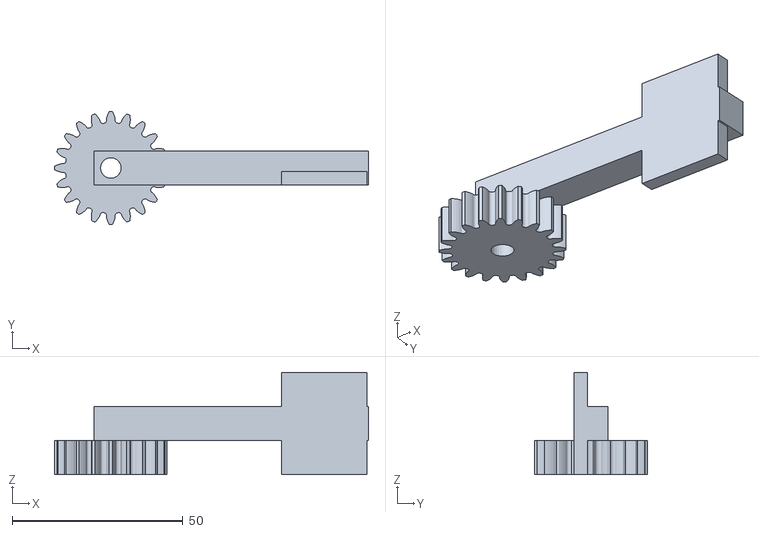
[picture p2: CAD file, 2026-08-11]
robot-arm 1/3D建模/左爪.stl
92.0 x 33.0 x 30.0

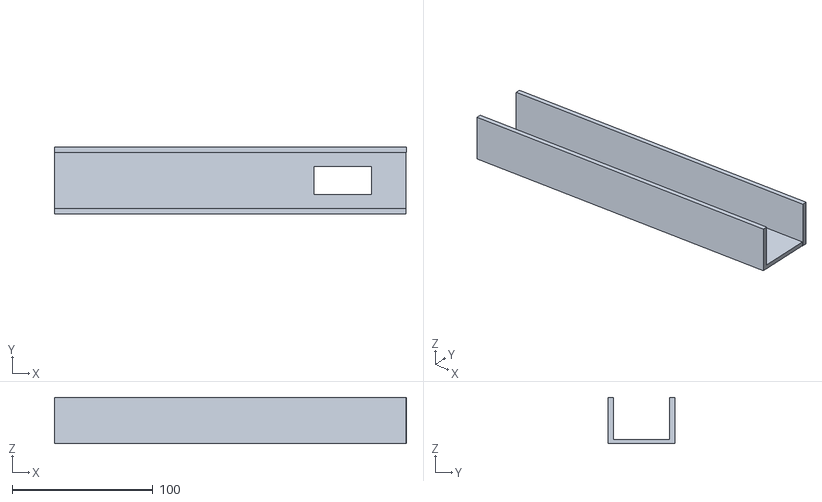
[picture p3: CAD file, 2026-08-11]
robot-arm 1/server/public/files/lower_arm.stl
250.0 x 47.3 x 33.0

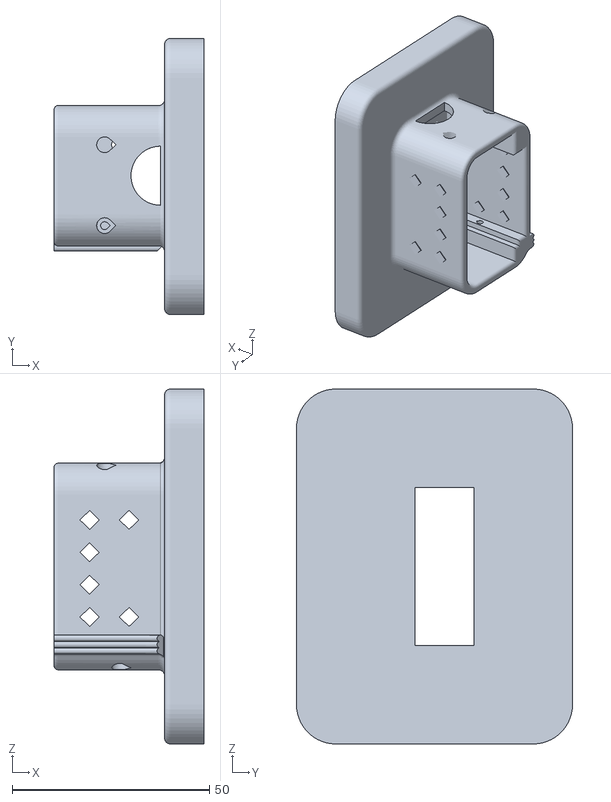
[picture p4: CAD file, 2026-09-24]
robot-arm2/hardware/stl/装配治具_mount_helper_v2.stl
38.0 x 70.0 x 90.0

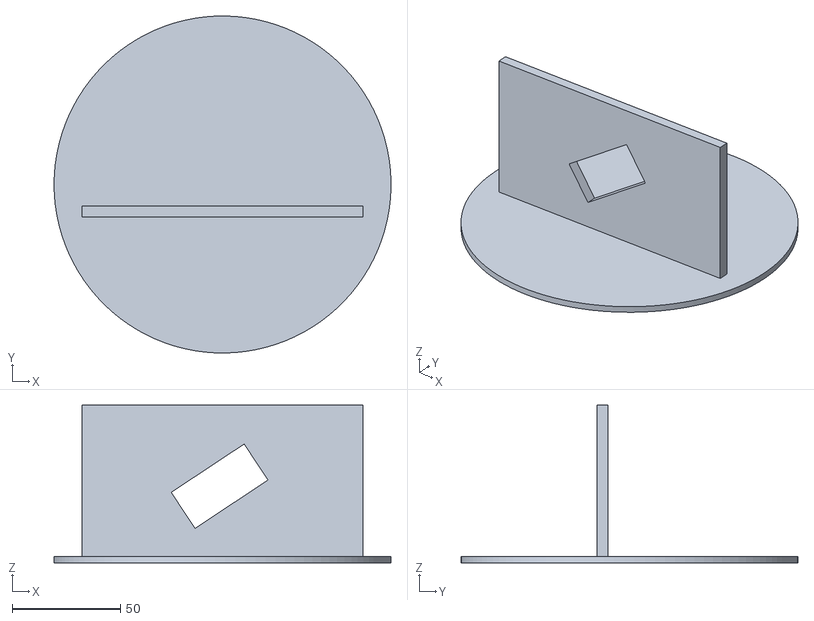
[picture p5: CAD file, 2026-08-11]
robot-arm2/server/public/files/elbow.stl
156.0 x 156.0 x 73.0

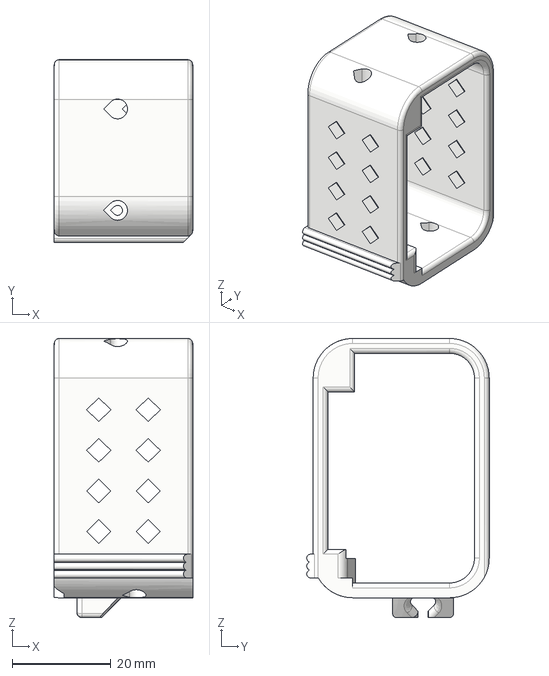
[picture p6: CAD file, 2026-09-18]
SO-ARM101/STEP/Motor_holder_SO101_Wrist.step
28.0 x 36.9 x 56.4 mm
Wiring_holder v1
Wiring_holder v1 (1)

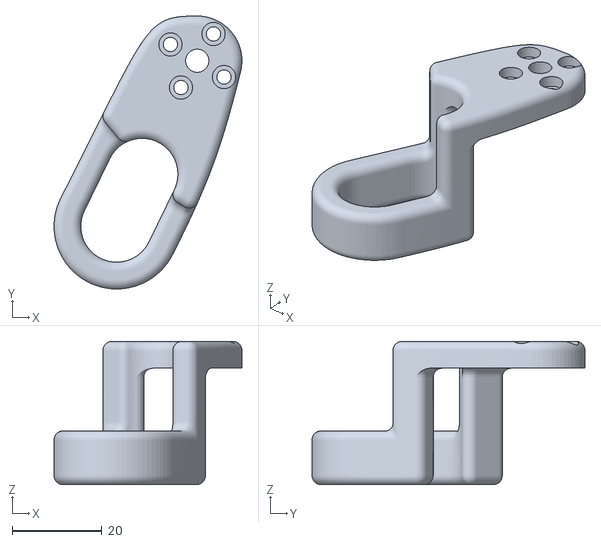
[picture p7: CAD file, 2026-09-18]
SO-ARM101/STL/Trigger_SO101.stl
42.0 x 61.0 x 32.0

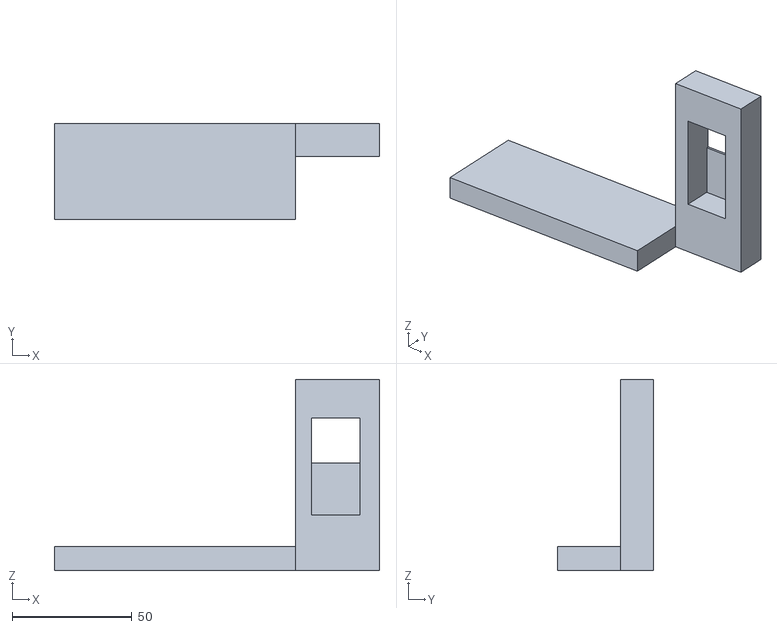
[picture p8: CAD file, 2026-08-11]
robot-arm 1/3D建模/手腕.stl
135.5 x 40.0 x 79.6

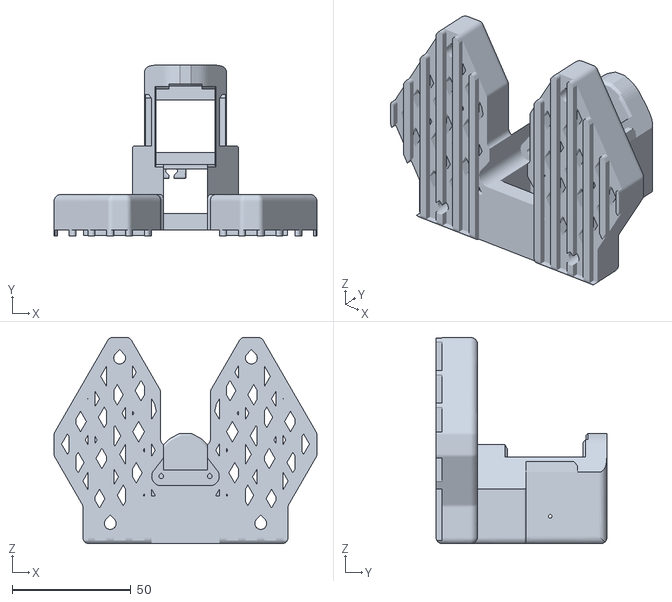
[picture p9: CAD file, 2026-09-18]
robot-arm2/hardware/stl/Base_SO101.stl
110.9 x 72.0 x 87.0

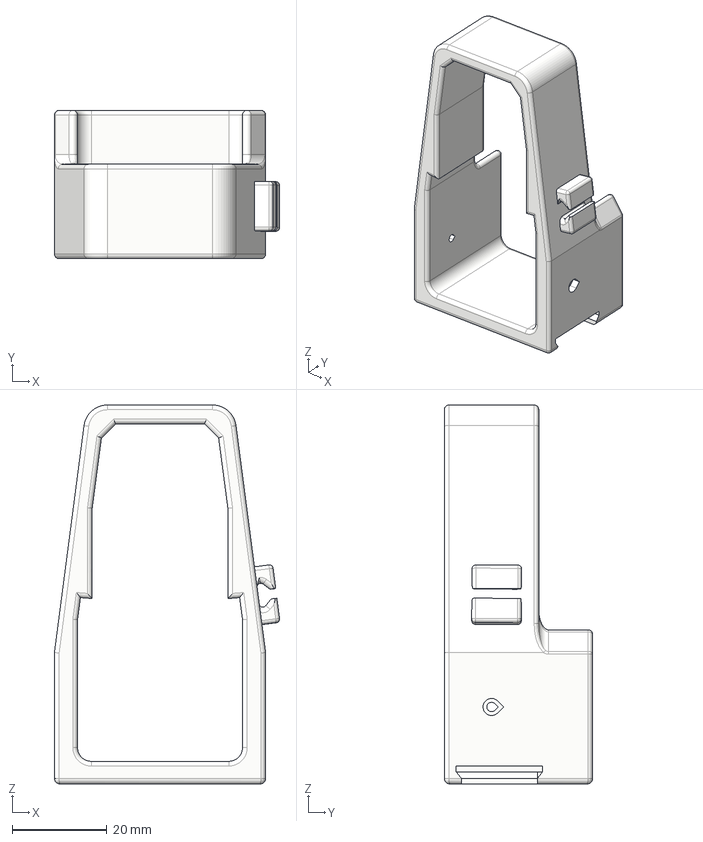
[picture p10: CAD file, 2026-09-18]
SO-ARM101/STEP/Base_motor_holder_SO101.step
47.6 x 31.4 x 80.2 mm

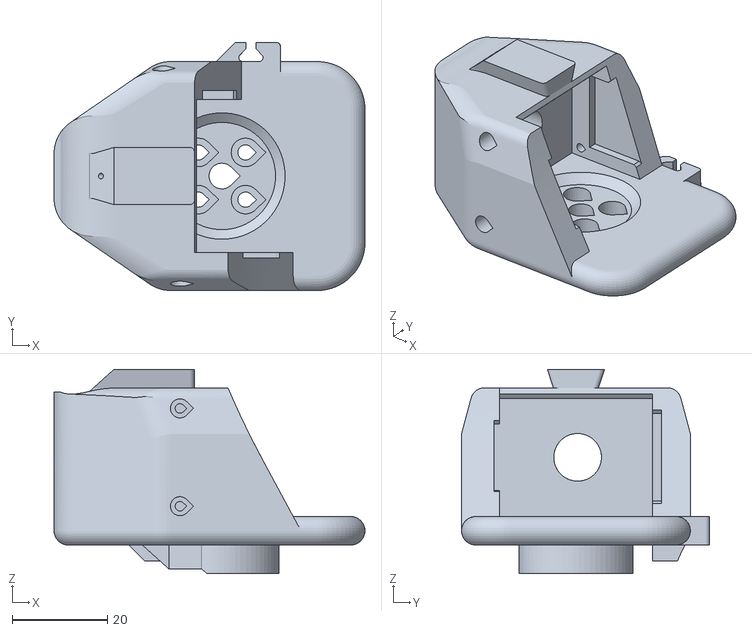
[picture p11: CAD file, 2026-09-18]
SO-ARM101/STL/Wrist_Roll_SO101.stl
65.2 x 52.0 x 42.8

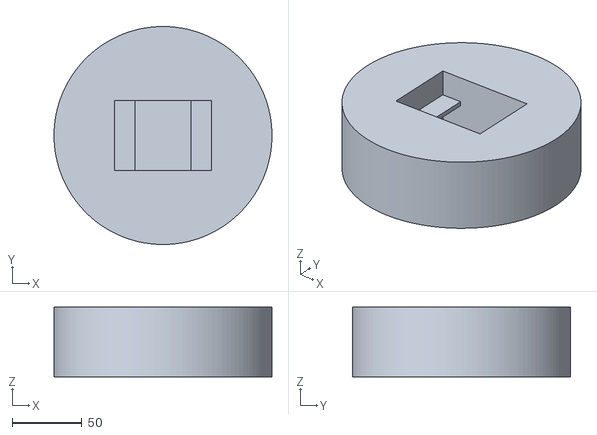
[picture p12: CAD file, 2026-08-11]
robot-arm 1/3D建模/底座.stl
156.6 x 156.6 x 50.0

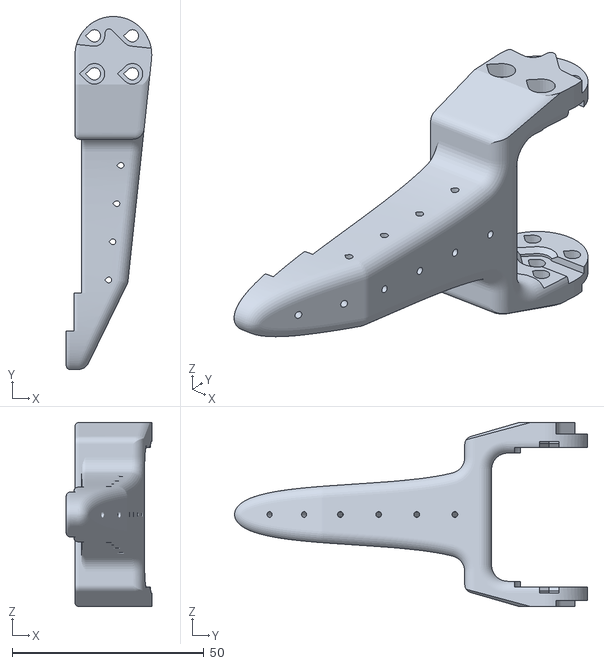
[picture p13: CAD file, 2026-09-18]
robot-arm2/hardware/stl/Moving_Jaw_SO101.stl
22.3 x 92.0 x 48.0

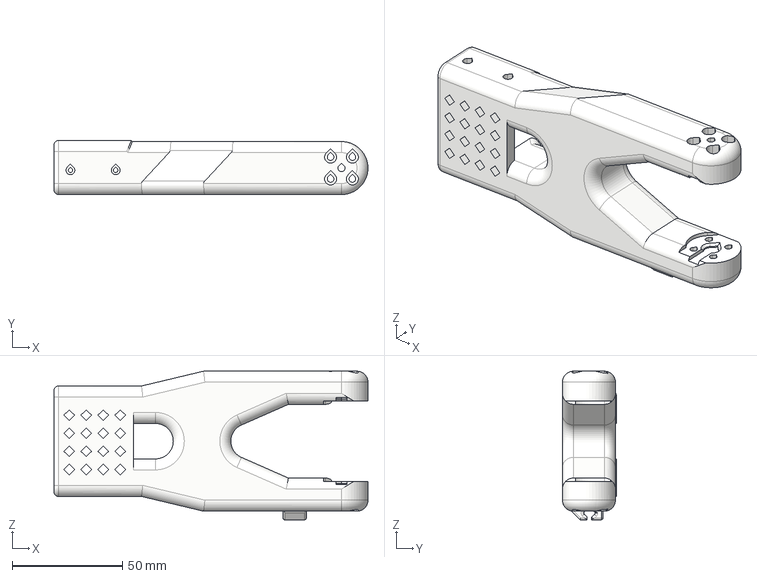
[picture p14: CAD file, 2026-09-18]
SO-ARM101/STEP/Upper_arm_SO101.step
142.2 x 24.5 x 67.3 mm
Wiring_holder v1
Wiring_holder v1 (1)

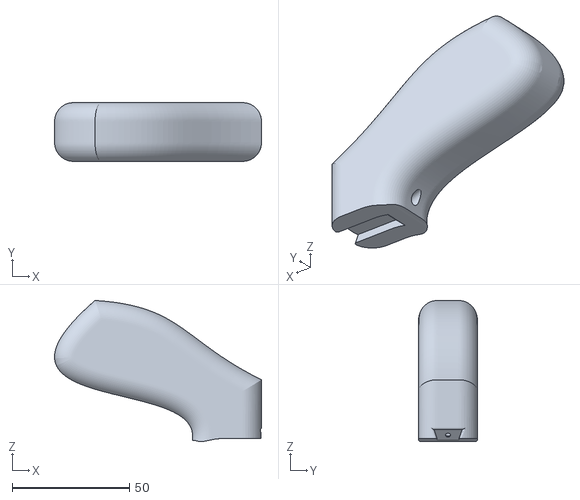
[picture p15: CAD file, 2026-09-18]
SO-ARM101/STL/Handle_SO101.stl
88.1 x 25.0 x 60.1

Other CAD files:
SO-ARM101/STEP/Base_SO101.step
SO-ARM101/STEP/Motor_holder_SO101_Base.step
SO-ARM101/STEP/Moving_Jaw_SO101.step
SO-ARM101/STEP/Rotation_Pitch_SO101.step
SO-ARM101/STEP/Seeedstudio_Mounting_Plate_SO101.step
SO-ARM101/STEP/Under_arm_SO101.step
SO-ARM101/STEP/WaveShare_Mounting_Plate_SO101.step
SO-ARM101/STEP/Wrist_Roll_Follower_SO101.step
SO-ARM101/STEP/Wrist_Roll_Pitch_SO101.step
SO-ARM101/STL/Seeedstudio_Mounting_Plate_SO101.stl
robot-arm 1/3D建模/右爪.stl
robot-arm 1/server/public/files/right_gripper.stl
robot-arm2/hardware/stl/Base_motor_holder_SO101.stl
robot-arm2/hardware/stl/Motor_holder_SO101_Base.stl
robot-arm2/hardware/stl/Motor_holder_SO101_Wrist.stl
robot-arm2/hardware/stl/Rotation_Pitch_SO101.stl
robot-arm2/hardware/stl/Under_arm_SO101.stl
robot-arm2/hardware/stl/Upper_arm_SO101.stl
robot-arm2/hardware/stl/WaveShare_Mounting_Plate_SO101.stl
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

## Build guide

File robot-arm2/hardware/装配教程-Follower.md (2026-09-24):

# SO-ARM101 Follower 装配教程

整理自官方装配指南（原文：<https://huggingface.co/docs/lerobot/so101>），
**只保留 Follower 相关部分**，Leader 的步骤已剔除。

## ⚠️ 网络说明

官方文档站和全部视频都托管在 **huggingface.co**，从当前网络**完全不可达**
（实测文档页、视频 CDN 三个端点全部超时）。本文是从 GitHub 上的源文件
（`huggingface/lerobot` → `docs/source/so101.mdx`）离线整理的，
**文字部分完整可离线使用**；视频需要代理才能看，链接见文末。

---

## 装配前

1. **清支撑**：把所有支撑料清干净。最省事的办法是用小螺丝刀从支撑底部撬。
2. **先插线**：电机装进结构件之前，先把那根 3-pin 线插到电机上——
   装进去之后再插会非常别扭。
3. **确认舵机型号**：Follower 六个关节**全部是 1/345 减速比**的同型号舵机
   （对应我们买的 C047）。不需要配比，装错了也不会装反型号。

## 装配顺序

> 螺丝规格只有两种：**M3×6**（平头）和 **M2×6**（尖头，自攻）。
> 「上舵盘」指随舵机附带的那个塑料舵盘。

### Joint 1（底座 / 肩部水平旋转）

1. 装上**两个**舵盘。上舵盘用 **1 颗 M3×6** 固定，下舵盘不需要螺丝。
2. 把 1 号电机放进底座。
3. 用 **4 颗 M2×6** 固定电机——**上面 2 颗、下面 2 颗**。
4. 套上第一个电机支架，用 **2 颗 M2×6** 固定（每侧 1 颗）。
5. 装上肩部件。
6. 肩部件用 **4 颗 M3×6**（顶面）+ **4 颗 M3×6**（底面）拧紧。
7. 装上肩部电机支架。

### Joint 2（肩部俯仰）

1. 装上两个舵盘，上舵盘 **1 颗 M3×6**，下舵盘不用螺丝。
2. 从**上方**滑入 2 号电机。
3. 用 **4 颗 M2×6** 固定。
4. 装大臂，**每侧 4 颗 M3×6**。

### Joint 3（肘部）

1. 装上两个舵盘，上舵盘 **1 颗 M3×6**，下舵盘不用螺丝。
2. 装入 3 号电机，用 **4 颗 M2×6** 固定。
3. 连接小臂到 3 号电机，**每侧 4 颗 M3×6**。

### Joint 4（腕俯仰）

1. 装上两个舵盘，上舵盘 **1 颗 M3×6**，下舵盘不用螺丝。
2. 套上 4 号电机支架。
3. 滑入 4 号电机。
4. 用 **4 颗 M2×6** 固定。

### Joint 5（腕旋转）

1. 把 5 号电机插入腕支架，用 **2 颗 M2×6** 固定（**正面**两颗）。
2. 腕电机上**只装一个**舵盘，用 **1 颗 M3×6** 固定。
3. 把腕部接到 4 号电机上，**两侧共 4 颗 M3×6**。

> 腕旋转件用的是 Follower 专用的 `Wrist_Roll_Follower_SO101.stl`——
> 别拿 Leader 的 `Wrist_Roll_SO101.stl`。

### Gripper（夹爪）

1. 把夹爪接到 5 号电机上——通过腕部那个舵盘连接，用 **4 颗 M3×6**。
2. 装入夹爪电机，**每侧 2 颗 M2×6** 固定。
3. 夹爪电机上装**两个**舵盘，上舵盘 **1 颗 M3×6**，下舵盘不用螺丝。
4. 装上活动爪，**两侧共 4 颗 M3×6**。

> 注意活动爪与固定爪的啮合方向，以及**水平轴螺丝孔里不能有支撑**。

### 螺丝总表

按原文逐条数出来的（只算 Follower）：

| 规格 | 数量 | 用途 |
|---|---|---|
| **M2×6** 尖头 | **22 ~ 24** | 舵机本体固定，自攻进塑料 |
| **M3×6** 平头 | **34 ~ 46** | 舵盘固定（6 颗）+ 结构件对接（28 颗起） |

**为什么 M3 是个区间**：原文几处写的是「每侧 4 颗 M3×6」，
可以读成「总共 4 颗（每边 2 颗）」也可以读成「每边 4 颗」。
按前者算 34，按后者算 46。

> ⚠️ 这里和官方螺丝包的数量对不上是正常的——官方那个包是**两臂共用**的 108 颗。
> 只做 Follower 用不了那么多。
> **实操建议：M3×6 直接买 50 颗以上**。螺丝几分钱一颗，
> 多买无害，少买了装到一半停工才是真麻烦。

逐关节明细（`M2` / `M3`）：

| 关节 | M2×6 | M3×6 | 说明 |
|---|---|---|---|
| Joint 1 底座 | 4 + 2 | 1 + 8 | 电机 4 颗；支架 2 颗；舵盘 1 颗；肩部件上下各 4 颗 |
| Joint 2 肩部 | 4 | 1 + 4 | 舵盘 1 颗；大臂 4 颗 |
| Joint 3 肘部 | 4 | 1 + 4 | 舵盘 1 颗；小臂 4 颗 |
| Joint 4 腕俯仰 | 4 | 1 | 只有舵盘 1 颗 |
| Joint 5 腕旋转 | 2 | 1 + 4 | 腕支架 2 颗；舵盘 1 颗；接 4 号电机 4 颗 |
| Gripper 夹爪 | 2 | 1 + 8 | 舵盘 1 颗；接 5 号电机 4 颗；活动爪 4 颗 |
| **合计** | **22** | **34** | 按「每侧=总共 4 颗」读 |

---

## 配置舵机（重要，容易踩坑）

### 出厂 ID 全是 1

**全新舵机出厂默认 ID 都是 `1`。** 总线上 ID 冲突就没法通信，
所以要**一个一个单独接上**，给每个舵机写一个唯一 ID（1~6）。

### 波特率也必须统一

总线上的通信速率由 baudrate 决定。**控制器和所有舵机必须设成同一个波特率**，
否则互相听不懂。STS3215 出厂默认 1 Mbps（和我们的固件 `SERVO_BAUD` 对齐）。

### 写进 EEPROM，只需要做一次

这两项写在舵机内部的**非易失存储（EEPROM）**里，掉电不丢，
所以**整个装配过程只需要做一次**。如果哪天把舵机挪作他用，再改回来就行。

> ⚠️ 改 ID 和波特率是写 EEPROM，官方建议**一个个单独接**来做，
> 不要六个全挂在总线上一起改——会改乱。

### 🔧 你的架构下的现实问题

官方的做法是把舵机接到 **Waveshare 总线舵机转接板**上，再用 USB 连电脑，
跑 `lerobot-*` 的 Python 命令或 Feetech 上位机来设 ID。

**但你的链路是 ESP32-S3 直接挂在 TTL 总线上（GPIO16/17），不经过 Waveshare 板。**
所以你面前有两条路：

1. **买一块 USB 转接板**（官方 BOM 里那块 ¥27 的 Motor Control Board），
   临时用电脑把 ID 设好再装到 ESP32 上。—— **最省事，强烈建议。**
   设 ID 是一次性的事，但没这块板就得自己写固件来实现。
2. **在自己的固件里实现设 ID**：往 EEPROM 的 ID 寄存器写值。
   技术上完全可行（你已经有 `writeByte` 那一套），但要小心——
   改 ID 会把总线上的寻址改掉，得一个舵机上电、设完拔掉、换下一个。

## 校准

官方的校准流程依赖 LeRobot Python 库，默认走 Waveshare USB 板。
你的架构不同，两条路：

1. **借用官方工具**：临时接 USB 转接板，用 Feetech 上位机或 LeRobot CLI 校准，
   把中位偏移量记下来。
2. **在自己固件里校准**：把每个关节的偏移量存进固件常量或服务器配置，
   在 `degToRaw` 那一层加上偏移。---- 和你的网页控制台更契合，
   甚至可以做一个「校准模式」页面：拖到机械零位，点一下就存偏移。

> 校准的本质只是「舵机的电气零位和机械零位差多少」，
> 存一组 6 个偏移量而已。不接官方工具也完全能做。

---

## 视频教程

### ✅ 首选：B 站幻尔科技中文系列（11 集，国内直连）

合集：**LeRobot SO-ARM机械臂详细教程**
<https://space.bilibili.com/470819482/channel/collectiondetail?sid=8530991>

**命名对照：`从臂` = Follower（你要的）；`主臂` = Leader（跳过）。**

| # | 标题 | 时长 | 链接 | 要不要看 |
|---|---|---|---|---|
| 1 | **从臂组装** | 11:08 | <https://www.bilibili.com/video/BV1ZoM76iEVW/> | ✅ **核心** |
| 2 | 主臂组装 | 9:46 | <https://www.bilibili.com/video/BV1a9gY6rErt/> | ⛔ 不需要 |
| 3 | 第一/第三视觉相机组装 | 2:11 | <https://www.bilibili.com/video/BV1qQ3F6oEj4/> | 🔶 装相机再看 |
| 4 | 主从臂接线 | 2:21 | <https://www.bilibili.com/video/BV17Q3F6ZEs2/> | 🔶 参考接线 |
| 5 | 主从臂校准 | 2:46 | <https://www.bilibili.com/video/BV1qD3F6tEiW/> | ✅ **需要** |
| 6 | 遥操作（不带第三视觉） | 1:25 | <https://www.bilibili.com/video/BV1gQ3q6pEqF/> | ⛔ 官方遥控路线 |
| 7 | 遥操作（带第三视觉） | 3:39 | <https://www.bilibili.com/video/BV13Q3q6pEGP/> | ⛔ 官方遥控路线 |
| 8 | **从臂 ID 设置** | 3:39 | <https://www.bilibili.com/video/BV1UsM16wEqq/> | ✅ **解决出厂 ID 全是 1** |
| 9 | 主臂舵机 ID 设置 | 3:02 | <https://www.bilibili.com/video/BV1aJM16iEPU/> | ⛔ 不需要 |
| 10 | 数据采集 | 5:01 | <https://www.bilibili.com/video/BV115un6dEp4/> | 🔶 做机器学习时看 |
| 11 | 模型推理 | 3:12 | <https://www.bilibili.com/video/BV1x5un6dEHB/> | 🔶 做机器学习时看 |

> 第 5、8 集正好覆盖上面「配置舵机」和「校准」两节，
> 而且是中文实拍，比文字好懂——那两个坑看视频比看文档快。

### 官方原版视频（在 huggingface.co，**当前网络不可达**）

需要代理才能看。把下面路径拼到 `https://huggingface.co` 后面：

| 内容 | 路径 |
|---|---|
| Joint 1 | `/datasets/huggingface/documentation-images/resolve/main/lerobot/Joint1_v2.mp4` |
| Joint 2 | `.../Joint2_v2.mp4` |
| Joint 3 | `.../Joint3_v2.mp4` |
| Joint 4 | `.../Joint4_v2.mp4` |
| Joint 5 | `.../Joint5_v2.mp4` |
| 夹爪 | `.../Gripper_v2.mp4` |
| 设置舵机 ID | `.../setup_motors_so101_2.mp4` |
| 校准 | `.../calibrate_so101_2.mp4` |

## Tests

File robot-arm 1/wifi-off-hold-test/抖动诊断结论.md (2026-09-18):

# 舵机静止抖动 · 诊断结论

## 现象
- 5 个舵机都能独立动，但静止锁定时有 2-3 个（实际所有）舵机小幅抽搐，**不同步**。
- 不承重（空载）也抖。

## 排除过的原因
| 怀疑对象 | 结论 |
|---|---|
| PCA9685 板 | 已拆、改直驱（arm-5servo）后仍抖 → 排除 |
| 舵机个体坏（电位器/死区） | 全部都会抖 → 排除"个别坏件" |
| 电压不足 / UBEC | 5V 20A 余量充足；空载也抖 → 排除欠压临界振荡 |
| 机械虚位 / 负载 | 空载也抖 → 排除 |

## 确诊方法（决定性实验）
烧录 `wifi-off-hold-test.ino`：**不开 WiFi，纯硬件 PWM 锁死 5 舵机**。
结果：**完全不抖**。

## 根因
**ESP32 的 WiFi 射频（含地弹）耦合进未屏蔽的信号线。**
静止时固件不再写 PWM，信号本是一条恒定脉宽；WiFi 发包瞬间的 RF 毛刺耦合进信号线，被模拟舵机当成一次微小角度变化 → 抽搐。不同舵机/不同时刻耦合强度不同 → 看起来"异步、小幅"。

## 整改清单（保留 WiFi 的前提下，按性价比排序）
1. **走线（零成本，最有效）**
   - 信号线尽量短，不要和 5V/12V 电源线并排长距离走。
   - 5 根信号线别抱成一束，能分开就分开。
   - ESP32（尤其板载天线一端）与舵机线束保持 ≥5cm 距离。
2. **地线星形接地**
   - 以 UBEC 输出端为唯一星点：UBEC GND / ESP32 GND / 分电盒 GND 三点在此汇合。
   - 不要让 ESP32 的回流电流走舵机的地线；加粗这根公共地。
3. **信号末端滤波**
   - 保留每根信号线 100Ω 串阻（磨圆边沿）。
   - 在**每只舵机的信号输入端对地**并联 1–4.7nF 电容，把 2.4GHz 射频滤掉（不影响 50Hz 脉宽）。
4. **软件配合**：如需更高定位精度，可在固件 loop 里周期性重写当前目标角，RF 偶发扰动后立即拉回目标。

## 复查方法
整改后烧录**完整版（含 WiFi/网页）**固件，静止 30 秒确认不再抽搐，再进入动作测试。

## 延伸（如果以后要彻底免疫这类抖动）
串行总线闭环舵机（如 Feetech STS3215 / STS3032）走总线协议 + 自带反馈，不依赖模拟 PWM 脉宽，天然免疫此类 RF 抖动，还能回传角度/电流做力反馈。预算允许可作为下阶段升级（见对话中的方案 B）。

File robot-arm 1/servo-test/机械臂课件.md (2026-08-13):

# 4舵机代码 · 保姆级讲解

---

## 1. PWM 控制舵机的原理

舵机里面有个小电路板，它不看电压高低，只看**橙线上高电平持续了多久**。

```
高电平持续 0.5 毫秒 → 舵机转到 0°
高电平持续 1.5 毫秒 → 舵机转到 90°
高电平持续 2.5 毫秒 → 舵机转到 180°
```

画出来就是这样：

```
0°:
████░░░░░░░░░░░░░░░░░░  0.5ms 高电平，剩下 19.5ms 低电平

90°:
██████████░░░░░░░░░░░░  1.5ms 高电平，剩下 18.5ms 低电平

180°:
██████████████████░░░░  2.5ms 高电平，剩下 17.5ms 低电平

|←──────── 20ms ───────→|  每 20ms 循环一次，1秒 50次 = 50Hz
```

你代码里对应的就是这两行：

```cpp
const int MIN_PULSE   = 500;   // 0°  时脉宽 500 微秒 = 0.5 毫秒
const int MAX_PULSE   = 2500;  // 180°时脉宽 2500 微秒 = 2.5 毫秒
```

**记一句话：脉宽越宽，转角越大。0.5ms → 0°，2.5ms → 180°，中间是线性的。**

---

## 2. 信号和电源是两回事

舵机的三根线，干的活不一样：

```
红线 (VCC) ─→ 供电  ┐
棕线 (GND) ─→ 回路  ├── 这俩走的是"力量"（大电流）
橙线 (SIG) ─→ 信号  ─── 这根走的是"信息"（小信号）
```

```
┌─────────────────────────────────────────┐
│                                         │
│   ESP32                     外部电源     │
│  ┌──────┐                ┌──────────┐  │
│  │ GPIO ├──→ 橙线(SIG) →│  舵机    │  │
│  │  GND ├──→ 共地 ────→│  红线 ← 外部电源+ │
│  └──────┘               │  棕线 ← 外部电源− │
│                         └──────────┘  │
│                                         │
│   ESP32 负责"说"（只发信号，不费电）      │
│   外部电源负责"干"（出力气）              │
└─────────────────────────────────────────┘
```

**ESP32 的 5V 引脚最多出 500mA 电流。一个 MG996R 舵机负载时就要 700-900mA，4个同时动要 10A。从 ESP32 取电 = 烧板子。**

---

## 3. 必须共地

```
正确 ✅                      错误 ❌

外部电源− ─┬─ 舵机棕线        外部电源− ── 舵机棕线
           ├─ ESP32 GND       ESP32 GND ── 悬空！
           │                  （什么都没接）
         两边的 GND 连在一起
```

**为什么必须连：**

ESP32 发信号，靠的是 "GPIO 和 GND 之间的电压差"。如果两边的 GND 没连在一起，舵机那边不知道你的"高电平"是相对于谁的高电平。

**类比：两个人量身高。你站在一楼量是 175cm，但另一个人站在三楼量，基准不一样，数字就全乱了。共地 = 两个人都站同一层楼。**

---

## 4. setup() 和 loop()

Arduino / ESP32 程序永远是这个结构：

```
程序启动
   │
   ▼
setup()  ← 只跑一次。初始化硬件、WiFi、舵机
   │
   ▼
loop()   ← 不断重复。处理网页请求、读传感器
   │
   └──→ loop() → loop() → loop() → ... 永远循环
```

你代码里：

```cpp
void setup() {
  // 初始化舵机、开 WiFi、启动 Web 服务器
  // 这些事只需要做一次
}

void loop() {
  server.handleClient();  // 检查有没有人访问网页，有就处理
}
```

---

## 5. 舵机初始化的三行代码

```cpp
servos[i].setPeriodHertz(50);                            // ① 设 PWM 频率 = 50Hz
servos[i].attach(servoPins[i], MIN_PULSE, MAX_PULSE);    // ② 绑到 GPIO，设脉宽范围
servos[i].write(currentAngle[i]);                        // ③ 转到初始角度 90°
```

**逐行解释：**

**① setPeriodHertz(50)** — "我要发 50Hz 的 PWM 信号"
- 50Hz = 每秒 50 个脉冲 = 每个周期 20ms
- 模拟舵机的标准频率，改了这个数舵机可能不认

**② attach(GPIO, 500, 2500)** — "用这个 GPIO 发信号，0°=500μs，180°=2500μs"
- 调用 attach 之后，GPIO 开始持续输出 PWM
- 舵机收到信号，开始受力锁住当前位置

**③ write(90)** — "转到 90°"
- 库自动算出 90° 对应 1500μs 脉宽
- 舵机收到 1500μs 脉冲 → 转到 90° 并停住

**这三行的顺序不能乱：先设频率 → 再绑引脚 → 最后写角度。**

---

## 6. HTTP 请求控制舵机的过程

你的手机浏览器访问 `http://192.168.4.1/set?servo=0&angle=45` 时：

```
手机浏览器                         ESP32
    │                                │
    │  GET /set?servo=0&angle=45     │
    │ ─────────────────────────────→ │
    │                                │  解析: servo=0, angle=45
    │                                │  constrain 检查范围
    │                                │  算出 PWM 脉宽
    │                                │  舵机 0 转到 45°
    │                                │
    │ ←───────── 45 ─────────────── │  返回当前角度
```

**你项目里有三个 URL：**

| URL | 干什么 |
|---|---|
| `http://192.168.4.1/` | 返回控制网页 |
| `http://192.168.4.1/angles` | 返回 4 个舵机的角度 `[90,45,30,120]` |
| `http://192.168.4.1/set?servo=0&angle=45` | 把舵机 0 转到 45° |

**关键认知：任何能发 HTTP 请求的东西都能控制你的机械臂——Python 脚本、手机 App、命令行……不只是那个网页。**

---

## 7. constrain() — 安全阀门

```cpp
int idx    = constrain(server.arg("servo").toInt(), 0, 3);
int target = constrain(server.arg("angle").toInt(), 0, 180);
```

如果有人恶意输入 `/set?servo=999&angle=500`：

```
没有 constrain:  servos[999].write(500) → 数组越界 → 程序崩溃
有 constrain:    idx=3, target=180 → 安全执行
```

**constrain(值, 最小, 最大)：超过最大就取最大，低于最小就取最小。**

---

## 8. 数组从 0 开始

```cpp
const int servoPins[4] = {13, 12, 14, 15};

servoPins[0] = 13   // 第 1 个舵机（底座）
servoPins[1] = 12   // 第 2 个舵机（大臂）
servoPins[2] = 14   // 第 3 个舵机（小臂）
servoPins[3] = 15   // 第 4 个舵机（手腕）
```

几乎所有编程语言数组都从 0 开始数。习惯它。

---

## 9. 平滑移动的代码

```cpp
int step = (target > currentAngle[idx]) ? 3 : -3;

while (abs(currentAngle[idx] - target) >= 3) {
    currentAngle[idx] += step;
    servos[idx].write(currentAngle[idx]);
    delay(25);
}
```

**人话翻译：**

1. 目标在当前位置的哪边？右边就走 +3°，左边就走 −3°
2. 只要离目标还差 3° 以上，就走一步，歇 25 毫秒
3. 循环往复，直到离目标不到 3°
4. 最后一步精确到位

**为什么不直接 `servo.write(目标)` 一步到位？**

直接跳过去 = 舵机瞬间全速转 = 机械臂会猛地甩过去。一步步走 = 平滑运动。代价是花的时间更长、耗电更多。

**步长 3° 和 delay(25) 是平衡点：既不太抖、也不太慢、也不让电源压力太大。**

---

## 10. WiFi AP 模式

```cpp
WiFi.softAP(ssid, password);
```

AP = Access Point = 热点。ESP32 自己变成一个微型路由器。

- 不需要家里有 WiFi
- 不需要路由器
- 手机直接连 ESP32 的 WiFi
- IP 地址固定是 `192.168.4.1`（记死这个地址）

---

## 11. 串口

```cpp
Serial.begin(115200);
```

ESP32 通过 USB 线跟你电脑聊天。你打开 Arduino IDE 的串口监视器就能看到打印的信息。

**115200 是波特率（通信速度），串口监视器必须选同一个数字，否则显示乱码。**

---

## 总结：你该记住的 8 条

| # | 内容 |
|:---:|---|
| 1 | PWM 控制舵机：0.5ms→0°，2.5ms→180°，50Hz |
| 2 | 信号和电源分离：ESP32 只发信号，电从外部走 |
| 3 | 必须共地：外部电源负极接 ESP32 GND |
| 4 | setup() 初始化一次，loop() 不断循环 |
| 5 | 初始化舵机三步：设频率→绑引脚→写角度 |
| 6 | HTTP URL 控制舵机：`/set?servo=编号&angle=角度` |
| 7 | constrain 防止越界，数组从 0 开始 |
| 8 | 平滑移动 = 一步步走 + delay，平衡速度和抖动 |

---

## 不用学的东西

- 网页 HTML/CSS 代码 —— 前端的事，跟嵌入式无关
- `R"rawliteral(...)"` —— C++ 语法糖，知道它能存网页字符串就行
- `PROGMEM` —— 把数据存 Flash 里，知道有这机制就行
- `[](){}`（lambda）—— 匿名函数，知道是"临时函数"就行
- LEDC 通道分配 —— 库自动帮你管了
- WiFi 协议栈细节 —— 知道 AP=开热点 就行

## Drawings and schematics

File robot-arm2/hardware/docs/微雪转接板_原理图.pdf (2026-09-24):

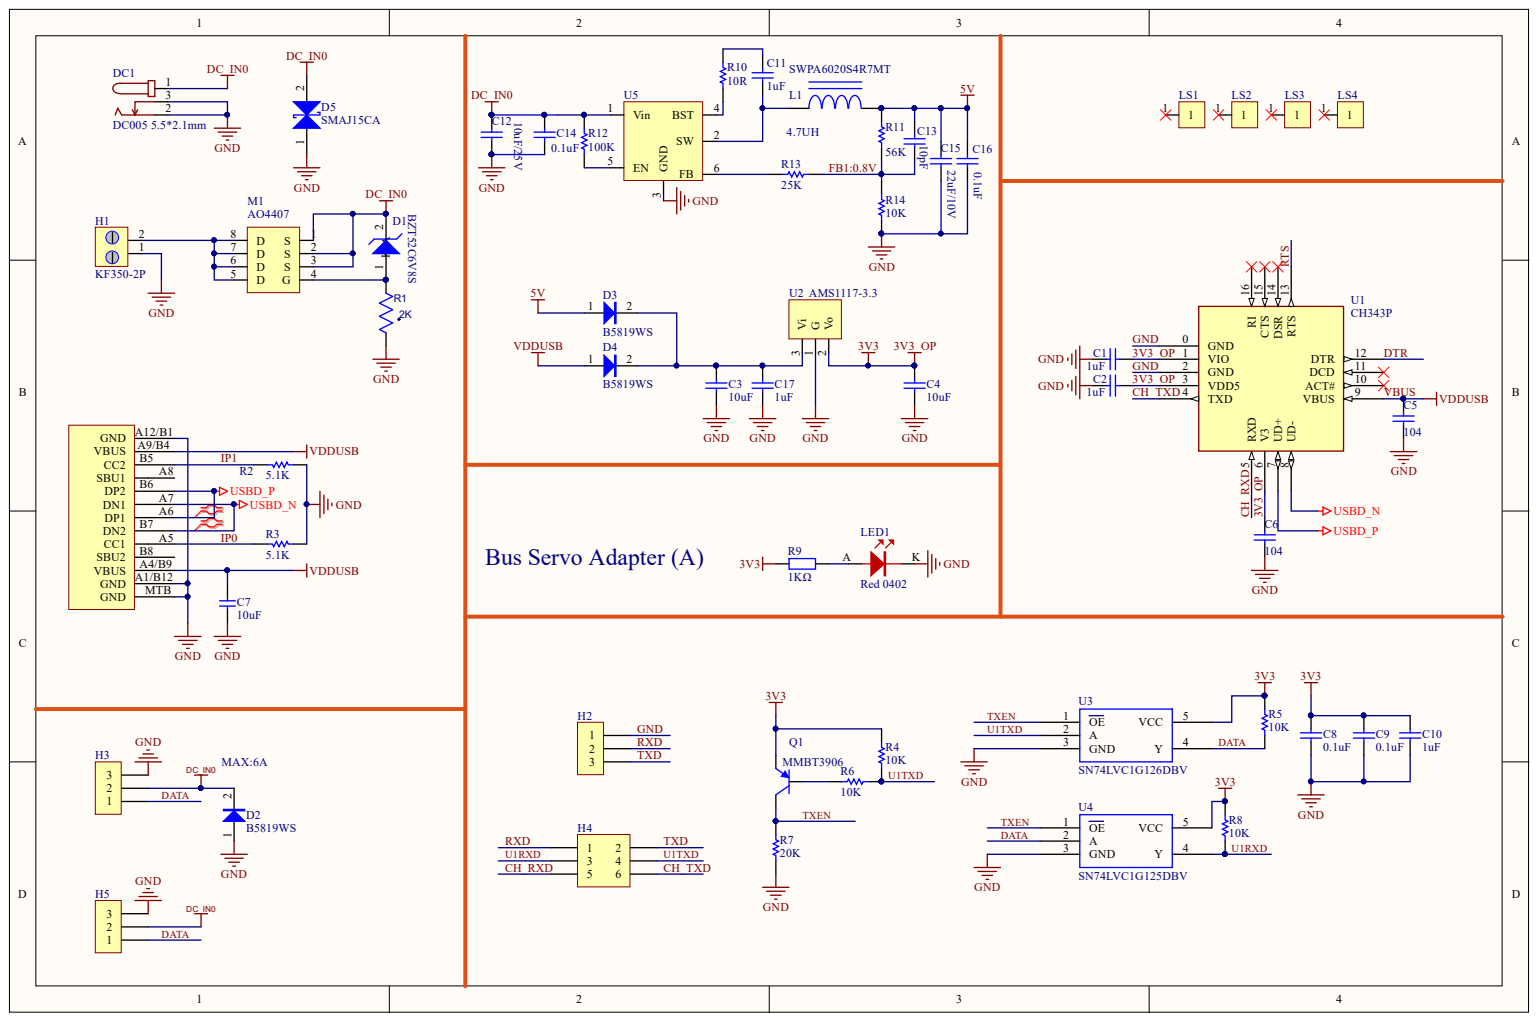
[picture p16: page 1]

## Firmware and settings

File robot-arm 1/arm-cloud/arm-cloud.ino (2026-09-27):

#include <WiFi.h>
#include <WebSocketsClient.h>
#include <HardwareSerial.h>

#include "secrets.h"   // WiFi 账号密码、服务器地址、token（不进 Git）

// ==================== 配置 ====================
#define SERVO_RX   16
#define SERVO_TX   17
#define SERVO_BAUD 1000000     // STS3215 出厂默认 1Mbps

const int NUM = 6;   // SO-ARM101 有 6 个关节
// 舵机 ID，按物理顺序从下到上：底座 → 肩 → 肘 → 腕俯仰 → 腕旋转 → 夹爪
// ⚠️ 出厂全是 1，必须逐个改成 1~6，否则总线冲突
uint8_t SERVO_ID[NUM] = {1, 2, 3, 4, 5, 6};
const char* NAMES[NUM] = {"底座", "肩部", "肘部", "腕俯仰", "腕旋转", "夹爪"};

const uint16_t POS_CENTER = 2048;   // 0~4095 对应 0~360°，2048 是 180°（机械中位）
const int MOVE_TIME = 400;          // 到达目标的毫秒数（舵机内部平滑）

// ---- 碰撞感知（自研部分）----
// 首次上机调试建议先设 0 关掉：此时阈值还没标定，可能误触发。
// 标定方法见文件末尾「负载标定」注释。
#define ENABLE_COLLISION 1

#define LOAD_ERR        0xFFFF   // 读寄存器失败时的返回值
#define LOAD_MASK       0x03FF   // 负载只有低 10 位是数值，见下面 pollJoint 的说明

const uint16_t LOAD_DELTA = 250;  // 负载「突变」阈值，不是绝对阈值（需标定）
const uint16_t LOAD_FLOOR = 120;  // 低于此值视为空载抖动，不判碰撞
const uint8_t  SPIKE_NEED = 2;    // 连续 N 次超阈值才认定，防单次抖动误报

// ---- 保护阈值（自研部分）----
// 3S 锂电：满电 12.6V，放到 10.5V 就该收了，再低会过放损坏电芯。
// 整机（6 个舵机同时使劲）能拉到 10V 以下，所以「停止」定在 10.0V。
const uint8_t  TEMP_WARN = 65;      // °C，超过就报警
const uint8_t  TEMP_STOP = 75;      // °C，超过就松力（再高温会退磁）
const uint16_t VOLT_WARN = 105;     // 0.1V 单位，即 10.5V
const uint16_t VOLT_STOP = 100;     // 10.0V

// ==================== STS/SCS 协议寄存器 ====================
#define REG_TORQUE_ENABLE  0x28
#define REG_GOAL_POSITION  0x2A
#define REG_GOAL_TIME      0x2C

// 只读区。刻意连成一片，好一次读完（见 pollJoint）。
// 0x38 ─┬─ 位置   ×2
//       ├─ 速度   ×2
//       ├─ 负载   ×2
//       ├─ 电压   ×1   （单位 0.1V）
//       ├─ 温度   ×1   （单位 1°C）
//       ├─ 异步写 ×1   （用不到，顺路读掉）
//       ├─ 状态   ×1   （用不到）
//       ├─ 运动中 ×1
//       ├─ 保留   ×2   ← 中间确实空着两个字节，别以为是漏写
// 0x45 ─┴─ 电流   ×2   （单位 6.5mA）
#define REG_PRESENT_POS    0x38
#define REG_TELEM_LEN      15     // 0x38 ~ 0x46，正好覆盖到电流

// 上面那片只读区在回包参数里的字节下标（参数从 buf[5] 开始）
#define TELEM_POS     0
#define TELEM_SPEED   2
#define TELEM_LOAD    4
#define TELEM_VOLT    6
#define TELEM_TEMP    7
#define TELEM_MOVING  10
#define TELEM_CURRENT 13

#define INST_PING        0x01
#define INST_READ        0x02
#define INST_WRITE       0x03
#define INST_SYNC_WRITE  0x83
#define BROADCAST_ID     0xFE

HardwareSerial servoBus(1);
WebSocketsClient ws;

// ==================== 状态 ====================
// ⚠️ 这里必须正好 6 个初值。少写一个的话，缺的那个元素默认 0，
//    上电「全部回中」时那个关节会直接甩到 0°（夹爪会被带到底）。
int target[NUM]     = {90, 90, 90, 90, 90, 90};  // 目标角度（网页的 0~180）
int prevTarget[NUM] = {90, 90, 90, 90, 90, 90};  // 上一个「确实到位」的角度，碰撞时退回这里

// 碰撞感知状态
uint16_t lastLoad[NUM];    // 上次采到的负载大小
uint8_t  spikeCnt[NUM];    // 连续突变计数
uint8_t  pollIdx = 0;      // 轮询指针：一次 loop 只读一个关节

// 保护状态（锁存：触发后要等条件真正恢复才解除，不然会反复触发）
bool     torqueOn      = false;
bool     overtempLatch = false;
bool     tempWarned    = false;
bool     lowbatLatch   = false;
uint8_t  lowVoltCnt    = 0;    // 连续低压计数，滤掉负载造成的瞬时压降

// 到位回报：发完指令后等 MOVE_TIME 再回报，避免高频刷屏
bool reportPending = false;
unsigned long reportAt = 0;

// ==================== 协议底层 ====================
/*
 * 包结构（Feetech SCS / Dynamixel 1.0 兼容）：
 *   [0] 0xFF  帧头
 *   [1] 0xFF  帧头
 *   [2] ID
 *   [3] LEN = 参数个数 + 2
 *   [4] 指令
 *   [5..] 参数
 *   [末] 校验和 = ~(ID + LEN + 指令 + 全部参数) 取低 8 位
 */
void sendPacket(uint8_t* p) {
  uint8_t total = 6 + (p[3] - 2);
  uint8_t sum = 0;
  for (uint8_t i = 2; i < total - 1; i++) sum += p[i];
  p[total - 1] = ~sum;
  servoBus.write(p, total);
  servoBus.flush();
}

void writeByte(uint8_t id, uint8_t reg, uint8_t v) {
  uint8_t p[7] = {0xFF, 0xFF, id, 4, INST_WRITE, reg, v};
  sendPacket(p);
}

void writeWord(uint8_t id, uint8_t reg, uint16_t v) {
  uint8_t p[8] = {0xFF, 0xFF, id, 5, INST_WRITE, reg,
                  (uint8_t)(v & 0xFF), (uint8_t)(v >> 8)};
  sendPacket(p);
}

/*
 * SYNC_WRITE：一条指令让所有舵机同时收到各自的目标位置。
 * 这是总线舵机相比 PCA9685 的优势之一 —— 5 轴严格同步启动，
 * 不会因为逐个发送而产生几毫秒的时序错位。
 */
void syncWritePosition(const uint16_t* pos, uint8_t num) {
  const uint8_t dataLen = 2;
  uint8_t params = 2 + (1 + dataLen) * num;
  uint8_t total = 6 + params;

  uint8_t p[40];
  if (total > sizeof(p)) return;

  p[0] = 0xFF; p[1] = 0xFF;
  p[2] = BROADCAST_ID;
  p[3] = params + 2;
  p[4] = INST_SYNC_WRITE;
  p[5] = REG_GOAL_POSITION;
  p[6] = dataLen;

  uint8_t k = 7;
  for (uint8_t i = 0; i < num; i++) {
    p[k++] = SERVO_ID[i];
    p[k++] = pos[i] & 0xFF;
    p[k++] = (pos[i] >> 8) & 0xFF;
  }
  sendPacket(p);
}

// ==================== 角度换算 ====================
// 网页的 0~180° 映射到舵机量程的一半（0~2048），另一半预留给需要更大行程的关节
uint16_t angleToPos(int a) {
  a = constrain(a, 0, 180);
  return (uint16_t)map(a, 0, 180, 0, POS_CENTER);
}

// 把当前所有目标角度一次性同步下发
void applyTargets() {
  uint16_t pos[NUM];
  for (int i = 0; i < NUM; i++) pos[i] = angleToPos(target[i]);
  syncWritePosition(pos, NUM);

  reportPending = true;
  reportAt = millis() + MOVE_TIME + 50;
}

/*
 * 开/关所有舵机的扭矩（＝松不松力）。
 *
 * 保护动作会调它。为什么不干脆断电：断电后手臂被重力拽下来会自由落体，
 * 松力则是「软下来」，舵机本身还有阻尼，落得慢得多。
 */
void setTorque(bool on) {
  if (torqueOn == on) return;      // 别重复下发，一帧 6 条包不便宜
  for (int i = 0; i < NUM; i++) {
    writeByte(SERVO_ID[i], REG_TORQUE_ENABLE, on ? 1 : 0);
  }
  torqueOn = on;
  // 告诉网页：现在是不是松力状态。网页靠它把控制条变灰并提示
  // 「已松力保护，处理完按恢复」—— 不然用户会以为机械臂坏了。
  ws.sendTXT("E:torque,," + String(on ? 1 : 0));
  Serial.printf("扭矩 %s\n", on ? "已开启" : "已关闭（松力）");
}

// ==================== 回读（力反馈用，需 1kΩ 上拉）====================
/*
 * 半双工总线：发完必须把 TX 释放成高阻态，舵机才能驱动同一条线回话。
 * 硬件上需要 TX 到 3.3V 接一个 1kΩ 上拉电阻。
 *
 * ⚠️ 这里用 pinMode(INPUT) 释放总线。ESP32 的 GPIO 矩阵理论上会把
 *    引脚一直钉在 UART 输出上，pinMode 未必真能释放。目前的用法
 *    沿袭自可用的参考实现，**第一次上机要先用示波器/逻辑分析仪确认
 *    回读有波形**；如果读回来的永远是 0xFFFF，就是这里没释放成功，
 *    改成读之前重新 servoBus.begin() 或 pinMatrixOutDetach()。
 *
 * 一次读一整片（15 字节），不是一格格读。
 * 为什么：每读一次要经历「发包 → 等回包 → 超时」，6 个关节分开读
 * 就是 6 倍的等待时间。而 loop() 里这段是阻塞的，等太久 WebSocket
 * 心跳会断（表现为"控制到一半掉线"）。合成一次读，代价降到 1/6。
 */
bool readTelemetry(uint8_t id, uint8_t* out, uint8_t len) {
  // 请求包：LEN=4 表示「指令 1 字节 + 参数 2 字节 + 校验 1 字节」
  uint8_t p[8] = {0xFF, 0xFF, id, 4, INST_READ, REG_PRESENT_POS, len, 0};
  sendPacket(p);

  pinMode(SERVO_TX, INPUT);        // 释放总线，等舵机回话

  // 回包长度 = 帧头2 + ID1 + LEN1 + 参数 len + 校验1
  uint8_t total = len + 5;
  uint8_t buf[24] = {0};
  uint8_t got = 0;
  uint32_t t0 = millis();
  while (got < total && millis() - t0 < 25) {
    if (servoBus.available()) buf[got++] = servoBus.read();
  }
  while (servoBus.available()) servoBus.read();   // 丢掉多余字节，别留到下一轮

  pinMode(SERVO_TX, OUTPUT);

  // 收全了才认。半路截断的数据比没数据更危险 —— 会解出乱七八糟的负载值。
  if (got < total || buf[0] != 0xFF || buf[1] != 0xFF || buf[2] != id) return false;

  // 回包里 [4] 是错误码（0 正常），参数从 [5] 开始
  if (buf[4] != 0) return false;
  memcpy(out, buf + 5, len);
  return true;
}

// ==================== 总线自检（自研部分）====================
/*
 * PING 一个 ID，收到回包说明舵机在线。
 *
 * 为什么需要：出厂舵机**全是 ID=1**，如果没逐个改，总线上会撞号，
 * 表现是「上电后什么都不动」——没有任何报错，只能靠猜。
 * 自检把缺的 ID 直接打出来，这类问题一眼就能定位。
 *
 * PING 的回包是最短的：0xFF 0xFF ID LEN ERR CHECKSUM 共 6 字节。
 */
bool pingServo(uint8_t id) {
  uint8_t p[6] = {0xFF, 0xFF, id, 2, INST_PING, 0};
  sendPacket(p);

  pinMode(SERVO_TX, INPUT);        // 释放总线，等回包
  uint8_t buf[6] = {0};
  uint8_t got = 0;
  uint32_t t0 = millis();
  while (got < 6 && millis() - t0 < 10) {
    if (servoBus.available()) buf[got++] = servoBus.read();
  }
  while (servoBus.available()) servoBus.read();
  pinMode(SERVO_TX, OUTPUT);

  return buf[0] == 0xFF && buf[1] == 0xFF && buf[2] == id;
}

// ==================== 遥测 + 碰撞 + 保护（自研部分）====================
/*
 * 一次 loop 只处理一个关节（轮询）。为什么不一口气读完 6 个：
 * readTelemetry 是阻塞的（要等回包），读 6 次累计能到几十毫秒，
 * 期间 ws.loop() 得不到调用，心跳就断了 —— 表现是"控制到一半掉线"。
 * 摊到 6 轮之后，每轮只阻塞几毫秒，心跳完全来得及。
 *
 * 服务器那边按关节号填格子，所以顺序、节奏都不敏感，
 * 掉一两轮也只是某个关节的数据晚一点刷新。
 */
void pollJoint() {
  uint8_t i = pollIdx;
  pollIdx = (pollIdx + 1) % NUM;

  uint8_t t[REG_TELEM_LEN];
  if (!readTelemetry(SERVO_ID[i], t, REG_TELEM_LEN)) {
    // 读失败就跳过这轮。不要拿旧值硬凑 —— 会解出假的负载突变。
    spikeCnt[i] = 0;
    return;
  }

  uint16_t pos     = t[TELEM_POS]     | (t[TELEM_POS + 1] << 8);
  uint16_t rawLoad = t[TELEM_LOAD]    | (t[TELEM_LOAD + 1] << 8);
  uint8_t  volt    = t[TELEM_VOLT];
  uint8_t  temp    = t[TELEM_TEMP];
  uint16_t current = t[TELEM_CURRENT] | (t[TELEM_CURRENT + 1] << 8);

  // 负载寄存器：低 10 位是大小（1000 = 额定扭矩的 100%），
  // **bit 10（0x400）才是方向位**。不是最高位 —— 最高位在这颗舵机上
  // 恒为 0，按最高位判方向会永远判成"逆时针"。
  uint16_t mag = rawLoad & LOAD_MASK;

  // ---- 上报遥测：原始值，不做换算 ----
  // 电压 ×0.1V、电流 ×6.5mA 这些单位换算全放在服务器做。
  // 固件只管把寄存器原样丢上去 —— 以后改显示、加图表，
  // 不用重新烧录一块拆下来很麻烦的板子。
  ws.sendTXT("T:" + String(i) + "," + String(pos) + "," + String(rawLoad) + ","
             + String(volt) + "," + String(temp) + "," + String(current));

  // ---- 保护：过温 / 低压 ----
  // 这两个是「慢变量」，不像碰撞那样几十毫秒跳变，
  // 所以顺路判掉，不用另开定时器。
  checkProtection(i, temp, volt);

  // ---- 碰撞判定 ----
  // 用 #if 而不是 if：关掉时这段彻底不编译，省下 flash 也避免
  // 一个"看起来在跑其实被短路"的假象。
#if ENABLE_COLLISION
  // 判据用「负载突变」而不是「负载超过某个值」——
  // 肩部关节静止托着整条手臂时本来就有持续负载（重力），
  // 用绝对阈值会在正常姿态下一直误报。撞到东西的特征是
  // 负载在几十毫秒内**跳变**。所以要的是 delta，不是绝对值。
  uint16_t delta = (mag > lastLoad[i]) ? (mag - lastLoad[i])
                                       : (lastLoad[i] - mag);
  lastLoad[i] = mag;

  if (delta < LOAD_DELTA || mag < LOAD_FLOOR) { spikeCnt[i] = 0; return; }
  if (++spikeCnt[i] < SPIKE_NEED) return;

  // ---- 认定碰撞：退回上一个到位位置 ----
  // 为什么不直接切扭矩：断电后手臂会被重力砸下来，比硬顶一下更危险。
  // 回退是「朝离开障碍物的方向」走，所以相对安全。
  spikeCnt[i] = 0;
  target[i] = prevTarget[i];
  applyTargets();

  Serial.printf("💥 %s 碰撞（负载 %u，突变 %u）→ 回退到 %d°\n",
                NAMES[i], mag, delta, target[i]);
  ws.sendTXT("E:collision," + String(i) + "," + String(mag));
#else
  lastLoad[i] = mag;   // 关掉碰撞也要跟住负载，不然重新打开时第一次必然误判
#endif
}

/*
 * 过温 / 低压保护。
 *
 * 为什么要做：舵机自己不会喊疼。堵转半个小时它只会烫到退磁，
 * 3S 锂电放到 9V 也只会安静地报废。这两个值都是"看一眼就知道"的，
 * 但没做保护就没人看。
 *
 * 过温只松力不锁死：锁死等于让它保持堵转，反而烧得更快。
 */
void checkProtection(uint8_t i, uint8_t temp, uint8_t volt) {
  if (temp >= TEMP_STOP && !overtempLatch) {
    overtempLatch = true;
    Serial.printf("🔥 %s 过温 %u°C（≥%u）→ 松力\n", NAMES[i], temp, TEMP_STOP);
    ws.sendTXT("E:overtemp," + String(i) + "," + String(temp));
    setTorque(false);
  } else if (temp >= TEMP_WARN && !tempWarned) {
    tempWarned = true;
    Serial.printf("🌡️  %s 温度偏高 %u°C\n", NAMES[i], temp);
    ws.sendTXT("E:overtemp_warn," + String(i) + "," + String(temp));
  } else if (temp < TEMP_WARN - 5) {
    // 带 5°C 迟滞：不然在阈值上下抖动会刷屏
    tempWarned = false;
    if (overtempLatch && temp < TEMP_WARN) {
      overtempLatch = false;
      setTorque(true);
      Serial.println("❄️  温度回落，恢复扭矩");
    }
  }

  // 电压：6 个舵机同时使劲时会被拉低，所以只看持续低压。
  // 单次低于阈值不报 —— 那是负载造成的正常压降，不是电池没电了。
  if (volt > 0 && volt < VOLT_WARN) {
    if (++lowVoltCnt >= 10 && !lowbatLatch) {   // 连续 10 轮（约几秒）
      lowbatLatch = true;
      Serial.printf("🪫 电压低 %u.%uV → 停手，请充电\n", volt / 10, volt % 10);
      ws.sendTXT("E:lowbat,," + String(volt));
      setTorque(false);
    }
  } else {
    lowVoltCnt = 0;
    if (lowbatLatch && volt >= VOLT_WARN) lowbatLatch = false;   // 换了电池就复位
  }
}

// ==================== WebSocket ====================
void onMessage(WStype_t type, uint8_t* payload, size_t length) {
  switch (type) {
    case WStype_CONNECTED:
      Serial.println("✅ 已连上服务器");
      break;

    case WStype_DISCONNECTED:
      Serial.println("❌ 与服务器断开，等待重连…");
      break;

    case WStype_TEXT: {
      String msg = String((char*)payload);
      msg.trim();
      Serial.println("收到命令: " + msg);

      // 命令格式: "舵机编号:角度"  例如 "0:45"
      int colon = msg.indexOf(':');
      if (colon > 0) {
        int idx = constrain(msg.substring(0, colon).toInt(), 0, NUM - 1);
        int tgt = constrain(msg.substring(colon + 1).toInt(), 0, 180);
        target[idx] = tgt;
        applyTargets();     // 立即下发，舵机自己平滑走位
        Serial.printf("  %s → %d°\n", NAMES[idx], tgt);
      }
      break;
    }

    default:
      break;
  }
}

// ==================== 入口 ====================
void setup() {
  Serial.begin(115200);
  delay(300);
  Serial.println("\n\n================================");
  Serial.println(" ESP32-S3 机械臂 · 云连接 + 总线舵机");
  Serial.println("================================");

  // ---- 总线舵机初始化 ----
  servoBus.begin(SERVO_BAUD, SERIAL_8N1, SERVO_RX, SERVO_TX);

  // ---- 总线自检：先确认谁在线，再开扭矩 ----
  // 放在开扭矩之前：如果 ID 撞号，宁可不动作，也不要让撞号的舵机乱转。
  Serial.print("总线自检: ");
  int online = 0;
  for (int i = 0; i < NUM; i++) {
    bool ok = pingServo(SERVO_ID[i]);
    Serial.printf("%d%s ", SERVO_ID[i], ok ? "✓" : "✗");
    if (ok) online++;
  }
  Serial.printf(" (%d/%d)\n", online, NUM);
  if (online < NUM) {
    Serial.println("⚠️ 有舵机没回应，常见原因：");
    Serial.println("   1) ID 没改 —— 出厂全是 1，会撞号，只能有一个应答");
    Serial.println("   2) 没共地 / 舵机没供电（ESP32 单独供电时最容易漏）");
    Serial.println("   3) DATA 接错 —— ESP32 TX 应经 1kΩ 上拉到总线 DATA");
  }

  for (int i = 0; i < NUM; i++) {
    writeWord(SERVO_ID[i], REG_GOAL_TIME, MOVE_TIME); // 设定到达时间
  }
  // ⚠️ 必须走 setTorque，不能直接写 REG_TORQUE_ENABLE。
  //    torqueOn 初值是 false，绕过 setTorque 的话这个变量就还是 false，
  //    而舵机实际已经上力了 —— 之后保护动作调 setTorque(false) 会因为
  //    "值没变" 被提前 return，**过温保护就成了哑炮**。
  setTorque(true);   // 开扭矩
  delay(100);
  applyTargets();   // 全部回中
  Serial.println("总线舵机初始化完成（全部回中 90°）");

  // ---- 连 WiFi（STA 模式）----
  Serial.printf("连接 WiFi: %s ", WIFI_SSID);
  WiFi.mode(WIFI_STA);
  WiFi.begin(WIFI_SSID, WIFI_PASSWORD);

  unsigned long startAt = millis();
  while (WiFi.status() != WL_CONNECTED && millis() - startAt < 20000) {
    delay(500);
    Serial.print(".");
  }

  if (WiFi.status() != WL_CONNECTED) {
    Serial.println("\n❌ WiFi 连接失败，检查 secrets.h");
    Serial.println("   （ESP32 只支持 2.4GHz，连不上 5GHz）");
    return;
  }
  Serial.println("\n✅ WiFi 已连接");
  Serial.print("   本机 IP: ");
  Serial.println(WiFi.localIP());

  // ---- 连服务器（token 放在连接地址里，服务器会校验）----
  // ⚠️ 路径必须是 /ws，不能是 /
  //    因为前面挂了 Nginx：/ 要留给静态首页，WebSocket 走独立路径 /ws。
  //    Nginx 无法按请求头区分 location，所以靠路径来分流。
  //    （服务器只校验 token 不校验路径，所以改路径不需要改后端）
  String path = "/ws?token=" + String(ESP32_TOKEN);
  ws.begin(SERVER_HOST, SERVER_PORT, path.c_str());
  ws.onEvent(onMessage);
  ws.setReconnectInterval(5000);
  ws.enableHeartbeat(15000, 3000, 2);

  Serial.printf("正在连接服务器 %s:%d …\n", SERVER_HOST, SERVER_PORT);
}

/*
 * ==================== 负载标定 ====================
 * LOAD_DELTA / LOAD_FLOOR 是估的，必须实测标定，否则会误触发。
 *
 *   1. 串口发 L → 打印 6 个关节当前负载
 *   2. 让机械臂**空载慢速走完全程**，记下每个关节负载的最大波动
 *      → LOAD_FLOOR 取这个波动的 1.5 倍左右
 *   3. 让机械臂自由运动中**用手轻挡一下**，记下负载跳变量
 *      → LOAD_DELTA 取「正常波动」和「阻挡跳变」之间，偏大一点更稳
 *   4. 都填回文件顶部，重新烧录
 *
 * 标定期间把 ENABLE_COLLISION 设 0，避免误触发干扰观察。
 */
void handleSerial() {
  if (!Serial.available()) return;
  char c = Serial.read();
  if (c != 'L' && c != 'l') return;

  Serial.print("负载: ");
  for (int i = 0; i < NUM; i++) {
    uint8_t t[REG_TELEM_LEN];
    if (!readTelemetry(SERVO_ID[i], t, REG_TELEM_LEN)) {
      Serial.printf("%s=-- ", NAMES[i]);      // -- = 没读到
      continue;
    }
    uint16_t raw = t[TELEM_LOAD] | (t[TELEM_LOAD + 1] << 8);
    Serial.printf("%s=%u ", NAMES[i], raw & LOAD_MASK);
  }
  Serial.printf(" (阈值 delta=%u floor=%u)\n", LOAD_DELTA, LOAD_FLOOR);
}

void loop() {
  ws.loop();     // 必须高频调用，否则收不到消息、心跳也会断

  handleSerial();

  // 一次 loop 轮询一个关节：既上报遥测，也顺带判碰撞和保护。
  // 关掉碰撞时也要跑 —— 遥测和过温/低压保护是另一回事，
  // 不能因为碰撞阈值没标定好就把力反馈一起关了。
  pollJoint();

  // 到位回报
  if (reportPending && millis() >= reportAt) {
    reportPending = false;

    // 到这里说明 MOVE_TIME 已过，各关节**确实到位**了。
    // 此刻才把 target 记进 prevTarget —— 碰撞回退要退回
    // 「真实到达过的位置」，而不是「发出过但可能没走到的指令」。
    for (int i = 0; i < NUM; i++) prevTarget[i] = target[i];

    String report = "";
    for (int i = 0; i < NUM; i++) {
      report += String(i) + ":" + String(target[i]);
      if (i < NUM - 1) report += ",";
    }
    ws.sendTXT(report);
    Serial.println("到位回报: " + report);
  }
}

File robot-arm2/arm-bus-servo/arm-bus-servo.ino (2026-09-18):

/*
 * ESP32-S3 + Feetech STS3215 总线舵机（第一版）
 *
 * ⚠️ 本固件按 Feetech 官方协议文档编写，尚未上机验证。
 *    第一次拿到舵机，请先按 README 的「四步验证法」逐个确认，别直接跑整套。
 *
 * ==================== 为什么换总线舵机 ====================
 * MG996R 是模拟 PWM 舵机，靠「量脉宽长度」决定角度。ESP32 的 WiFi 射频
 * 耦合进信号线，脉宽被撑长或削短，舵机就当成一次角度变化 → 静止抽搐。
 *
 * STS3215 走数字串口协议，每条指令带校验和。噪声混进来要么被电平阈值
 * 滤掉，要么校验失败被舵机直接丢弃 —— 永远不会被「翻译成角度」。
 * 所以静止时纹丝不动，这是协议层面免疫，不是靠滤波压制。
 *
 * ==================== 供电（和之前完全不同）====================
 *   STS3215 额定 7.4V（范围 6–8.4V），**不是 5V**！
 *   - 方案A：2S 锂电直驱 7.4V（推荐，最省事）
 *   - 方案B：现有 12.6V 锂电 → 降压模块到 7.4V（≥5A）
 *   之前的 UBEC 5V 20A 用不上了。
 *
 *   每个舵机堵转电流约 2–3A，5 个同时动峰值很大：
 *   供电线要粗（≥20AWG），地线同样要粗。
 *
 * ==================== 接线（一条 3 线总线手拉手）====================
 *   5 个舵机的 DATA 全部并联成一条总线
 *   5 个舵机的 V+ / GND 分别并到 7.4V / GND
 *
 *   ESP32 GPIO17 (TX) ──[1kΩ]──→ 总线 DATA
 *   ESP32 GPIO16 (RX) ──────────→ 总线 DATA
 *   ESP32 GND         ──────────→ 舵机 GND（必须共地）
 *
 *   ⚠️ 只发指令时，TX 直连即可。
 *   ⚠️ 要回读（力反馈/读角度）时，必须加 1kΩ 上拉到 3.3V，
 *      因为总线是半双工的，发完要把 TX 释放成高阻态才能让舵机说话。
 *
 * ==================== 舵机 ID ====================
 *   出厂全是 ID=1！必须逐个改成 1~5，否则总线冲突。
 *   用本固件的串口命令 `id <旧ID> <新ID>` 逐个改，
 *   或者买 Feetech 官方 FE-URT-1 调试板用图形界面改（更省事）。
 *
 * ==================== 串口命令（115200）====================
 *   help              显示帮助
 *   scan              扫描总线上有哪些 ID
 *   ping <id>         测试某个舵机是否在线
 *   id <旧id> <新id>  修改舵机 ID（改完断电重启才生效）
 *   move <id> <角度>  单个舵机转到指定角度（0~180）
 *   all <角度>        所有舵机转到同一角度
 *   center            全部回中（90°）
 *   torque <id> <0|1> 关闭/打开扭矩（改 ID 前必须先关）
 *   w                 开启 WiFi + 网页控制
 */

#include <WiFi.h>
#include <WebServer.h>
#include <HardwareSerial.h>

// ==================== 配置 ====================
#define SERVO_RX        16
#define SERVO_TX        17
#define SERVO_BAUD      1000000     // STS3215 出厂默认 1Mbps

const char* WIFI_SSID = "RobotArm-Test";
const char* WIFI_PASS = "12345678";

const int NUM = 6;   // SO-ARM101 有 6 个关节
// 改好 ID 后填这里，顺序 = SO-ARM101 自下而上
uint8_t SERVO_ID[NUM] = {1, 2, 3, 4, 5, 6};
const char* NAMES[NUM] = {"底座", "肩部", "肘部", "腕俯仰", "腕旋转", "夹爪"};

const uint16_t POS_MIN = 0;         // 0°
const uint16_t POS_MAX = 4095;      // 360°
const uint16_t POS_CENTER = 2048;   // 180°（舵机机械中位）

const int MOVE_TIME = 300;          // 到达目标的毫秒数（舵机硬件平滑）

// ==================== STS/SCS 协议寄存器 ====================
#define REG_TORQUE_ENABLE  0x28
#define REG_GOAL_POSITION  0x2A
#define REG_GOAL_TIME      0x2C
#define REG_PRESENT_POS    0x38     // 当前位置（只读）
#define REG_PRESENT_LOAD   0x3C     // 当前负载/电流（只读，力反馈用）

#define INST_PING   0x01
#define INST_READ   0x02
#define INST_WRITE  0x03
#define INST_SYNC_WRITE 0x83

#define BROADCAST_ID 0xFE

HardwareSerial servoBus(1);
WebServer server(80);
bool wifiOn = false;

// ==================== 协议底层 ====================
/*
 * 包结构（Feetech SCS / Dynamixel 1.0 兼容）：
 *   [0] 0xFF        帧头
 *   [1] 0xFF        帧头
 *   [2] ID
 *   [3] LEN = 参数个数 + 2
 *   [4] 指令
 *   [5..] 参数
 *   [末] 校验和 = ~(ID + LEN + 指令 + 全部参数) 取低 8 位
 */
void sendPacket(uint8_t* p) {
  uint8_t total = 6 + (p[3] - 2);   // LEN 已包含指令和校验和
  uint8_t sum = 0;
  for (uint8_t i = 2; i < total - 1; i++) sum += p[i];
  p[total - 1] = ~sum;
  servoBus.write(p, total);
  servoBus.flush();
}

// 写寄存器：reg 起始地址，data 为要写的 n 个字节
void writeReg(uint8_t id, uint8_t reg, const uint8_t* data, uint8_t n) {
  uint8_t p[6 + 8];
  if (n > 8) return;
  p[0] = 0xFF; p[1] = 0xFF; p[2] = id;
  p[3] = n + 3;        // 参数 = 1个地址 + n个数据 → LEN = (1+n) + 2
  p[4] = INST_WRITE;
  p[5] = reg;
  for (uint8_t i = 0; i < n; i++) p[6 + i] = data[i];
  sendPacket(p);
}

// 便捷：写 1 字节
void writeByte(uint8_t id, uint8_t reg, uint8_t v) {
  writeReg(id, reg, &v, 1);
}

// 便捷：写 2 字节（小端）
void writeWord(uint8_t id, uint8_t reg, uint16_t v) {
  uint8_t d[2] = { (uint8_t)(v & 0xFF), (uint8_t)(v >> 8) };
  writeReg(id, reg, d, 2);
}

// 同步写：一条指令让所有舵机同时到达目标（5 轴协调运动的关键）
void syncWritePosition(const uint16_t* pos, uint8_t num) {
  const uint8_t dataLen = 2;
  uint8_t params = 2 + (1 + dataLen) * num;   // 地址 + 数据长度 + (ID+数据)*个数
  uint8_t total = 6 + params;

  uint8_t p[40];
  if (total > sizeof(p)) return;

  p[0] = 0xFF; p[1] = 0xFF;
  p[2] = BROADCAST_ID;
  p[3] = params + 2;
  p[4] = INST_SYNC_WRITE;
  p[5] = REG_GOAL_POSITION;
  p[6] = dataLen;

  uint8_t k = 7;
  for (uint8_t i = 0; i < num; i++) {
    p[k++] = SERVO_ID[i];
    p[k++] = pos[i] & 0xFF;
    p[k++] = (pos[i] >> 8) & 0xFF;
  }
  sendPacket(p);
}

// ==================== 回读（力反馈用，需要 1kΩ 上拉）====================
/*
 * 半双工总线：ESP32 发完必须把 TX 释放成高阻态，舵机才能驱动同一条线回话。
 * 硬件上需要 TX 到 3.3V 接一个 1kΩ 上拉电阻。
 */
void readReg(uint8_t id, uint8_t reg, uint8_t n, uint8_t* out) {
  uint8_t p[8];
  p[0] = 0xFF; p[1] = 0xFF; p[2] = id;
  p[3] = 4;              // 参数 = 地址 + 读取长度
  p[4] = INST_READ;
  p[5] = reg;
  p[6] = n;
  sendPacket(p);         // 注意：sendPacket 里已 flush

  // 释放总线，让舵机能回话
  pinMode(SERVO_TX, INPUT);

  // 读回包：FF FF ID LEN ERR 数据... 校验和
  uint8_t expect = 6 + n;
  uint8_t got = 0;
  uint32_t t0 = millis();
  while (got < expect && millis() - t0 < 20) {
    if (servoBus.available()) out[got++] = servoBus.read();
  }
  while (servoBus.available()) servoBus.read();   // 清干净

  pinMode(SERVO_TX, OUTPUT);
}

// 读当前位置（0~4095）
uint16_t readPosition(uint8_t id) {
  uint8_t buf[10] = {0};
  readReg(id, REG_PRESENT_POS, 2, buf);
  if (buf[0] != 0xFF || buf[1] != 0xFF) return 0xFFFF;   // 没收到有效回复
  return buf[5] | (buf[6] << 8);
}

// 读当前负载（力反馈：负载 ≈ 力矩，夹爪抓握力度/碰撞检测用）
uint16_t readLoad(uint8_t id) {
  uint8_t buf[10] = {0};
  readReg(id, REG_PRESENT_LOAD, 2, buf);
  if (buf[0] != 0xFF || buf[1] != 0xFF) return 0xFFFF;
  return buf[5] | (buf[6] << 8);
}

// ==================== 上层动作 ====================
uint16_t angleToPos(int a) {
  // 0~180° 映射到舵机量程的一半（0~2048），机械中位在 2048
  a = constrain(a, 0, 180);
  return (uint16_t)map(a, 0, 180, POS_MIN, POS_CENTER);
}

void setTorque(uint8_t id, bool on) {
  writeByte(id, REG_TORQUE_ENABLE, on ? 1 : 0);
}

void moveOne(uint8_t id, int angle) {
  writeWord(id, REG_GOAL_POSITION, angleToPos(angle));
}

void moveAll(int angle) {
  uint16_t pos[NUM];
  for (int i = 0; i < NUM; i++) pos[i] = angleToPos(angle);
  syncWritePosition(pos, NUM);
}

// 逐个开扭矩 + 设运动时间（舵机硬件平滑，不用软件 delay 循环）
void initServos() {
  for (int i = 0; i < NUM; i++) {
    setTorque(SERVO_ID[i], true);
    writeWord(SERVO_ID[i], REG_GOAL_TIME, MOVE_TIME);
  }
}
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

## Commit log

2026-08-11 feat: WiFi STA模式连接手机热点
    [下臂.stl, 右爪.stl, 左爪.stl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]
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2026-08-15 refactor: 舵机信号/电源分离接线，新增直驱诊断代码，清理无用文件
    - servo-test.ino: 信号走 PCA9685、电源走 2进12出盒，调慢转动速度
    - servo-direct.ino: 新增 ESP32 直驱单舵机诊断代码
    - 删除 .DS_Store 和旧的 servo-single.ino
    - 新增根目录 .gitignore
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2026-08-16 feat: 产品官网(留言板/下载/PWA) + WebSocket设备鉴权
    多页面网站、留言板、PWA、下载页、纯黑主题；WebSocket加token鉴权防设备冒充；config.js移出版本库，用config.example.js作模板
    [base.stl, elbow.stl, left_gripper.stl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]
2026-09-18 feat: 手势识别控制 + 留言板接入 MySQL
    新增 gesture-control/（MediaPipe 手势识别控制机械臂）
    - 分层：手势判定 / 通信 / 主程序，手势逻辑不依赖摄像头，可脱离硬件单测
    - 14 个单元测试全部通过
    - 用「指尖到掌心的距离」判定手指伸展，不受手掌朝向和远近影响
    - 两种模式：手势指令 / 手掌位置跟随
    留言板从 JSON 文件存储改为 MySQL
    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
2026-09-18 feat: 新增总线舵机固件（STS3215）与升级文档
    从 MG996R 模拟 PWM 舵机升级到 Feetech STS3215 串行总线舵机。
    根因：模拟舵机靠脉宽长度决定角度，WiFi 射频耦合进信号线会让脉宽被
    误读成角度变化。加电容电阻只是在信号完整性层面压制噪声，治标不治本。
    总线舵机走数字协议且带校验和，噪声要么被电平阈值滤掉、要么校验失败
    被舵机丢弃，属于协议层面的免疫。
    固件 arm-bus-servo.ino：
    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
2026-09-18 refactor: 遥控页改用 Vue 3 + Vite 重写
    用 Vue 3 单文件组件替代原来的单文件 control.html。
    结构：
    - App.vue 主页面：布局 + 预设姿态 + 组合子组件
    - ServoCard.vue 单个舵机控制卡片，defineModel 实现双向绑定
    - useArmControl.js 控制逻辑抽成 composable（角度状态/节流/API 调用）
    设计要点：
    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
2026-09-18 docs: 接入 Swagger 接口文档 + 补充服务器总览文档
    Swagger（swagger-jsdoc + swagger-ui-express）：
    - /api-docs 在线可调试的文档页
    - /api-docs.json 原始 OpenAPI 规范，可导入 Postman/Apifox
    - 注解以 JSDoc 形式写在路由上方，文档与代码同步维护
    - 覆盖全部 5 个接口：遥控 + 留言板的增删改查
    定义了 Message / Reply / Error 三个可复用数据模型，
    并在 /set 的文档里说明了 503 是「设备离线」的判断依据。
    新增 server/README.md：
    - 系统架构图与「为什么需要服务器中转」的说明
    - 快速开始、npm 脚本、目录结构、接口速查、环境变量
    - 把 D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
2026-09-18 feat: 新增云连接版固件，打通 ESP32 与服务器的链路
    此前项目存在断层：现有固件都是 WiFi.softAP 自建热点（局域网直连），
    而 server/ 是 WebSocket 中转架构、等待设备主动连入 —— 两者从未打通。
    本固件从 git 历史中的早期版本恢复并升级，实现 ESP32 主动连出：
    - WiFi STA 模式连接路由器
    - WebSocket 客户端接入 Node 服务器，带 token 鉴权
    - 非阻塞运动控制：改为主循环分步推进，多轴并行且 loop 保持响应
    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
2026-09-18 docs: 新增系统技术文档
    从硬件层到应用层，完整说明整个系统由什么组成、怎么运作、
    以及每个技术选择背后的原因。
    组织结构：
    - 系统总览：四层架构图、五个自由度定义
    - 一次完整的数据流：从拖动网页滑块到舵机转动，逐层追踪九个环节
    - 硬件层：舵机工作原理、为何需要 PCA9685、供电设计
    - 嵌入式层：两种固件模式对比、非阻塞运动控制、心跳保活
    - 云服务层：为何需要服务器中转（三种方案对比）、设备鉴权、
    两个具体的数据库优化
    - 关键问题：抖动问题的完整排查过程与两种解决思路
    - 应用层：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
2026-09-18 docs: 新增根目录 README
    仓库此前缺少门面文档 —— 打开首页只看到一堆目录，看不出这是什么项目、
    怎么运行、有什么亮点。
    内容包括：
    - 功能特性与四层架构图（含"为什么需要服务器中转"的说明）
    - 三步快速开始（启服务 / 烧固件 / 手势控制）
    - 九个子目录的导航与文档索引
    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
2026-09-18 feat: 新增云端+总线舵机合并固件，补充固件演进记录
    arm-cloud-bus/ —— arm-cloud 与 arm-bus-servo 的合并版本：
    保留 WiFi STA + WebSocket 客户端 + token 鉴权，
    底层驱动从 PCA9685 换成 STS3215 串行总线。
    与 PCA9685 版的关键差异：
    - 不再需要软件插补：把「目标位置 + 到达时间」一起下发，
    舵机内部按时间平滑走位，主循环无需逐度推进
    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
2026-09-18 refactor: 按阶段拆分为 robot-arm 1 / robot-arm2 两个版本
    第一代（robot-arm 1/，2026-08-16 状态）：
    - 从提交 ae99c60 导出，共 32 个文件
    - 定位：打通云端链路，实现公网遥控
    - 内容：3D建模 + 云控服务器（Node + JSON 存储）+ 基础固件
    第二代（robot-arm2/，当前版本）：
    - 第一代的全部内容 + 后续所有工作
    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
    [base.stl, elbow.stl, left_gripper.stl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]
2026-09-18 refactor: 按内容新旧重新划分（旧的归档、新的独立可运行）
    上一版按"时间"切分，把仍然沿用的旧成果物也放进了第二代，
    实际上它们属于第一代且已被取代。
    调整后：
    移出 robot-arm2（只留在 robot-arm 1）：
    - 3D建模/ MG996R 尺寸的原模型（正在重新建模）
    - arm-5servo/ 直驱实验固件
    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
    [下臂.stl, 右爪.stl, 左爪.stl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]
2026-09-18 refactor: MG996R 固件全部归档，robot-arm2 只保留总线舵机方案
    换舵机的决策已经确定，第二代不应再保留模拟舵机时代的固件。
    归档到 robot-arm 1：
    - arm-cloud/ 云连接 + PCA9685
    - wifi-off-hold-test/ 抖动诊断实验（含诊断结论文档）
    robot-arm2 现状：
    - arm-cloud-bus/ 云连接 + 总线舵机（当前主线）
    - arm-bus-servo/ 总线舵机固件（含串口调试命令）
    - server/ 与舵机型号无关，一行未改
    - gesture-control/ 同上
    即两个固件全部面向总线舵机，而 server 与手势模块只跟 HTTP 接口
    打交道，换舵机对它们完全透明。
    同步修正所有跨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
    [arm-cloud.ino, wifi-off-hold-test.ino]
2026-09-18 docs: 新增第一代系统技术文档，重点记录抖动排查过程
    robot-arm 1/技术文档.md —— 与第二代文档对应，覆盖：
    系统构成与技术决策：
    - 为什么用 PCA9685（后被排查过程反向验证）
    - 为什么让 ESP32 主动连出（三种方案对比）
    - 为什么加 token 鉴权
    ★ 完整的抖动排查过程：
    - 问题的发现（08-15）与排查思路
    - 逐步排除表（五个怀疑对象各自的验证方法与结论）
    - 一个反直觉的发现：绕开 PCA9685 改直驱反而更糟，
    反向验证了干扰源就是 ESP32 本身
    - 决定性实验（09-02）：关 WiFi 后完全不抖
    - 当时的整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
2026-09-18 refactor: 从 5 舵机迁移到 6 舵机（适配 SO-ARM101 结构）
    机械结构确定采用 SO-ARM101 开源设计（Hugging Face LeRobot 项目的
    官方硬件），该设计为 6 自由度，原代码中写死的 5 舵机假设需全部更新。
    关节命名（与舵机编号一致，自下而上）：
    0 底座旋转 1 肩部 2 肘部 3 腕俯仰 4 腕旋转 5 夹爪
    改动范围：
    - arm-cloud-bus.ino / arm-bus-servo.ino：NUM 5→6，ID 1-6，关节命名
    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
2026-09-18 feat: 机械臂控制加登录鉴权，WebSocket 路径改为 /ws
    一、控制接口加登录（防止陌生人乱动机械臂）
    控制页仍然公开可见，但控制需要密码：
    POST /api/login 密码换 token，写入 httpOnly cookie
    POST /api/logout 退出登录
    GET /api/auth 查询登录状态
    GET /set 新增 requireAuth 中间件
    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
    [Base_SO101.step, Base_SO101.stl, Base_motor_holder_SO101.step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]
2026-09-18 docs: SO-ARM101 模型目录补充署名与来源说明
    上一提交误将下载的第三方模型文件一并提交（12MB）。
    经核查上游为 Apache-2.0 许可证，允许再分发，故保留，
    但必须补上署名与许可证副本（Apache-2.0 的强制要求）。
    新增：
    - SO-ARM101/LICENSE 上游原版 Apache-2.0 许可证
    - SO-ARM101/README.md 来源、许可、目录说明、打印注意事项
    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
2026-09-18 feat: 登录接口加频率限制，防短密码被暴力破解
    控制密码可能设得比较短，而接口暴露在公网、原本没有任何限流 ——
    脚本每秒能试几千次，短密码几分钟就被爆破。
    策略：同一 IP 在 10 分钟内失败 5 次，封禁 15 分钟。
    - 存内存（重启清空，对个人站点够用）
    - 定期清理过期记录，避免内存增长
    - 登录成功清空该 IP 的失败计数
    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
2026-09-20 feat: 统一管理员身份 —— 登录一次即可管理全站
    原来留言板的回复/删除每次都要在请求体里传密码，前端每次弹 prompt，
    很繁琐。改成与会话统一的「登录一次即为管理员」。
    服务端：
    - /api/messages/:id/reply 和 DELETE 改用 requireAuth 中间件
    （原来是在 body 里比对 password）
    - requireAuth 的 401 响应由纯文本改为 JSON，便于前端统一处理
    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
2026-09-20 feat: 全站账号系统 —— 注册/登录/权限，第一个注册者自动为管理员
    原来是「一个共享密码」，所有人用同一个口令，分不清谁是谁。
    改为真正的用户系统：访客注册账号（用户名+密码+昵称）后登录，
    管理员可控制机械臂、回复和删除留言。
    - schema.sql: accounts 表（用户名/昵称/密码哈希/角色）
    sessions 表（会话存数据库而非进程内存 ——
    这样 Python 的图书管理服务能查同一张表校验 token，
    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
2026-09-20 feat: 全站改为黑白配色 + 星空背景
    按需求把深蓝底 + 青色高亮（#1a1a2e / #00e5ff）统一改为纯黑白，
    并给所有页面加上缓慢闪烁的星空背景。
    新增 public/starfield.js —— 全站共用的星空脚本：
    - 页面只需 <script src="/starfield.js"></script>，canvas 自动插入
    - 三层星星做纵深感，各层不同频率正弦明暗变化
    - 支持 devicePixelRatio 高清屏，窗口缩放会重建
    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
2026-09-20 fix: Service Worker 改为网络优先，修复「改了看不到」
    原来用的是缓存优先：
    caches.match(req).then(r => r || fetch(req))
    安装时把 / 等 8 个资源写进缓存后，之后永远直接返回缓存、
    从不询问服务器 —— 服务器更新多少次都看不到新内容。
    实际踩到：首页改版后，主浏览器刷新多次仍是旧页面，
    换浏览器/手机访问却立刻是新的，才确认是 SW 的锅。
    改动：
    - 缓存策略改为「网络优先」：先请求网络，成功则返回新内容
    并顺手更新缓存；请求失败（离线）才回退到缓存
    - 缓存版本 robot-arm-v1 → v2，新 SW 激活时会清掉旧的
    -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
2026-09-20 fix: 新版控制台缺 #sky 样式，星空画布把内容顶下去了
    根因：starfield.js 只是往页面插一个 <canvas>，它本身不带任何样式。
    旧版页面用的是 public/style.css，那里有 #sky 的定位规则；
    新版是 Vue 独立构建的，全局样式在 web/src/style.css —— 而那份里
    **没有** #sky 规则。于是画布变成一个普通块级元素，占满整屏高度，
    把控制面板整个推到下面去了。
    表现就是用户说的：「要往下拉」「没从星光透出来」。
    修法：
    - web/src/style.css 补上 #sky 的固定定位 + z-index:0 + 不挡点击
    - App.vue 的 .nav 和 .container 补上 position/z-index，
    免得被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
2026-09-20 fix: 样式表改名 style.css → site.css，绕开 Service Worker 的旧缓存
    现象：旧版控制台（/control/v1）星空不成背景、内容被顶下去；
    新版（/control）正常。
    根因：**旧版页面用的 /style.css 被 Service Worker 缓存死了**。
    第一版 sw.js 的预缓存列表里有 '/style.css'：
    const ASSETS = ['/', '/control', '/messages', '/download',
    '/style.css', '/app.js', ...];
    而它是"缓存优先"，一旦写进缓存就永远不再问服务器。
    于是新增的 #sky 定位规则根本送不到浏览器 —— 画布没有 fixed 定位，
    变成普通块级元素，占一整屏高度把内容推下去。
    新版不受影响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
2026-09-20 fix: 第一代云连接固件改用 /ws 路径
    robot-arm 1 的 arm-cloud.ino 还在用早期的 "/?token=" 连接路径。
    网站前面挂了 Nginx 之后，/ 被静态首页占用，
    WebSocket 必须走独立的 /ws —— 否则握手请求会被当成访问首页，
    拿到一段 HTML 而不是升级成 WebSocket，设备根本连不上。
    同步更新：
    - secrets.h.example 补上公网部署的配置说明（服务器 IP + 端口 80），
    并注明「端口用 80 走 Nginx，不要填 3000」
    - 本地 secrets.h 已填好服务器参数（WiFi 密码留空待填），该文件不进库
    编译验证：esp32s3，82% 空间占用。
    [arm-cloud.ino]
2026-09-20 fix: ESP32 重连时被误判为离线
    现象：机械臂控制到一半，状态灯突然变灰、指令发不出去，
    但串口显示设备仍连着服务器。
    日志还原：
    22:39~22:43 正常收发（浏览器命令 → ESP32 回报）
    22:43:37 ✅ ESP32 认证通过 ← 设备重连，新连接进来
    22:43:53 ESP32 断开 ← 旧连接这时才被检测到
    （此后设备被标记离线，实际它还连着）
    根因：原代码用 if (!esp32) 判断是否登记，只认第一条连接。
    设备重连时旧连接往往还没被 TCP 检测为断开（NAT/路由丢包时尤其明显），
    新连接就被忽略；等旧连接随后真正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
2026-09-21 fix: 限流阈值过严导致并发时大量 503/429
    用户反馈"多个并发就瘫痪"。压测复现：
    首页 50并发 → 41×200 + 9×503
    API 50并发 → 49×503
    （503 是 nginx limit_req 的默认状态码，看起来就像服务挂了）
    原因是我半小时前刚加的限流设得太严，而且有个更隐蔽的坑：
    **拖动滑块时前端每 60ms 发一次请求，拖十秒就是 160+ 个 /set，
    必然撞上"120 次/分钟"的全局限流 —— 正常操作反而被拦。**
    两处调整：
    - 全局限流 120/分钟 → 300/分钟（5 次/秒，比正常浏览宽裕得多）
    - /set 加进豁免名单 —— 它是"用起来就会高频"的接口，
    靠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
2026-09-24 chore: 二代硬件资料、诊断固件与 STL 打印件
    - stl/：SO-ARM101 Follower 打印件 12 件（取自 TheRobotStudio/SO-ARM100，Apache-2.0）
    - 装配教程-Follower.md：离线整理的装配步骤，Leader 部分已剔除
    - servo-tools/：Feetech 官方 SDK + bench.py（scan/info/id/move/torque），
    不依赖固件就能独立验证总线
    - polarity-scan/ loopback-test/ uart-bridge/ sniffer/：排查「ESP32 打不通舵机」
    期间写的四个诊断固件。polarity-scan 能不拔线一次试完两种极性，最快
    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
    [Base_SO101.stl, Base_motor_holder_SO101.stl, Motor_holder_SO101_Base.stl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]
2026-09-24 fix: 固件首次读到舵机回包 —— 引脚错 + 半双工没释放
    两个根因都不在协议层：
    1. 开发板丝印的 TX/RX 是 GPIO43/44（UART0），固件用的是 GPIO16/17。
    线接 43/44 时自发自收一个字节都收不到，现象是"死一样的安静"。
    2. pinMode(SERVO_TX, INPUT) 摘不掉 UART —— GPIO 矩阵把引脚一直钉在 TX 输出上，
    回包开头被顶坏（FE FE 00 FE | FF FF 01 02 00 FC）。readTelemetry() 只认
    buf[0]==0xFF，于是整包丢弃，表现为「自检停在 1/6、负载全是 --」。
    改为 esp_rom_gpio_connect_out_signal(..., SIG_GPIO_OUT_IDX, ...) 摘信号，
    收完用 uart_set_pin() 挂回。
    串口新增两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
    [arm-cloud-bus.ino]
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2026-09-24 feat: 台面联调放开监听 + 假 ESP32 模拟器 + 密码工具
    - server.js：新增 BIND_HOST 环境变量。默认仍是 127.0.0.1（生产经 Nginx），
    台面联调时 ESP32 在局域网上够不到 127.0.0.1，需 BIND_HOST=0.0.0.0。
    不设这个变量时行为完全不变。
    - simulator/fake-esp32.js：伪装成真机连服务器，带简化物理模型（位置平滑趋近、
    肩肘扛重力），可伪造 collision/overtemp/lowbat。硬件没到货也能验证
    「服务器 → 浏览器」这条链。⚠️ 它与真 ESP32 抢同一个连接位，二选一。
    - tools/password.js：离线验证 / 重置账号密码。密码是 scrypt 单向哈希，忘了只能重置；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
2026-09-27 fix: 手势控制发不出指令 —— 登录少发用户名，外加三个连带问题
    四个问题叠在一起，症状都一样：识别明明正常，机械臂一动不动。
    1. 登录只发了 password，没发 username。服务端是
    accounts.login(username, password)，拿 undefined 去查必然「查无此人」，
    一律 401 —— 而 401 的文案是「用户名或密码错误」，看着像密码错，
    真正缺的字段完全看不出来。
    副作用不小：每次启动都白送 5 次失败登录，正好撞上防爆破限流
    （同 IP 连错 5 次封 15 分钟），连网页登录一起封掉。
    2. 发送失败完全静默。动作的返回值没人看，登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
2026-10-24 feat: 修正手势误判，新增「收拢」姿态
    - 拇指不参与判定：实测握拳被读成点赞、四指被读成张开，
    改成只数食指~小指（0~4），小指单独特判；去掉「数字4」
    - 新增 🤘（食指 + 小指）= 收拢：六个关节叠回最紧凑的姿态
    - --dry-run 改用空客户端，不再真的发请求
    - 新增 --token：用已有会话 token 跳过登录（台面联调用）
    - 单元测试补到 22 个，覆盖拇指误判的各种组合
2026-10-24 docs: 补充上机演进记录，修正自由度表述
    - 新增 robot-arm2/演进记录.md：第二代上机联调的完整踩坑过程
    - 技术文档补充遥测数据流与力反馈章节
    - 供电方案改为 3S 12.6V 直通（C047 支持 4–14V，无需降压）
    - 「六自由度」改为「五自由度（含夹爪）」：实际是 5 个关节 + 1 个夹爪，
    共 6 个舵机 —— 面试官会追问第 6 个自由度是哪
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2026-10-25 fix: 保护阈值改成串口可调，遥测坏帧重试一次
    排查「过载保护从没触发过」时发现两个问题：
    1. 阈值是编译期常量，验一次要重烧一次板子，没法用小负载把
    触发链路跑一遍。改成 c/k/m/d 四个串口命令现场修改
    （临界值 / 解除值 / 持续时间 / 碰撞突变），S 命令会把当前值打出来。
    2. 正常运行时每个关节每秒约有 9 次读到坏帧（回包开头被总线抢线顶坏）。
    单帧丢失不影响显示，但过载保护是按「持续 3 秒」判的，
    坏帧一多计时就凑不满。改成读失败重试一次，重试后计数归零。
    另外加了读取失败计数（S 命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
2026-10-25 diag: 定位过载保护失效的根因 —— 满载堵转时舵机停止回包
    真机堵转复现：负载 1000 顶了 20 秒，保护不动，连 10 秒的「持续高负载」
    提醒都没发（两者在同一个函数里）。加「连续读失败」上报后确认为：
    被顶住的肘部舵机在满负载下不再响应读寄存器，25 秒内 168 次读取全失败，
    其余 5 个关节零失败。按「持续时间」判的保护因此永远凑不满 3 秒。
    - 固件：连续读失败计数并上报（E:telemfail / E:telemok）；
    过载计时开始也发 E:loadtimer（原来只有串口打印，不在电脑边看不见）
    - 演进记录：新增坑 14，附现场数据；修正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
2026-10-25 docs: 补上夹爪真机堵转验证，过载保护端到端确认
    夹爪两片中间卡硬物，39° → 0° 合上：
    1.04s 13° 负载 812 → 顶住
    2.09s 13° 负载 72 → 保护动作，停在原地不再挤
    事件 {"type":"stall","joint":5,"value":784}
    约 1.6 秒触发，等于 MOVE_TIME(400) + 宽限(1200)，走的是超时判据。
    峰值负载只有 784 < LOAD_CRIT 850 —— 旧判据这次根本不会触发，
    说明换成看门狗不是优化，是换了正确的判据。
2026-10-25 fix: 碰撞阈值按实测标定，250 → 500
    快速大幅动作本身就会让负载剧烈跳变，和"撞上去"信号一样，
    阈值 250 压在正常动作区间里，误判是必发不是偶发。
    新增 deltaPeak（每条指令的最大负载突变，S 命令可读）后实测：
    400ms 快档跑 10 个大幅动作，正常峰值最高 300（肘部 0→60）；
    真被手顶住时单次突变 800+。取 500，两头都留余量。
    阈值 500 下重跑 12 个动作（含肘部 0→90），零误判。
    - 顶部注释补上标定数据与取值理由
    - 负载标定那段重写，改成可复现的步骤（d1000 → 1 → 逐关节 S）
    - 演进记录新增坑 15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
